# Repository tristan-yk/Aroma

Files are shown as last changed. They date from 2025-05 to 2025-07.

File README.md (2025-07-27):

# Aroma Control Board

<p align="center">
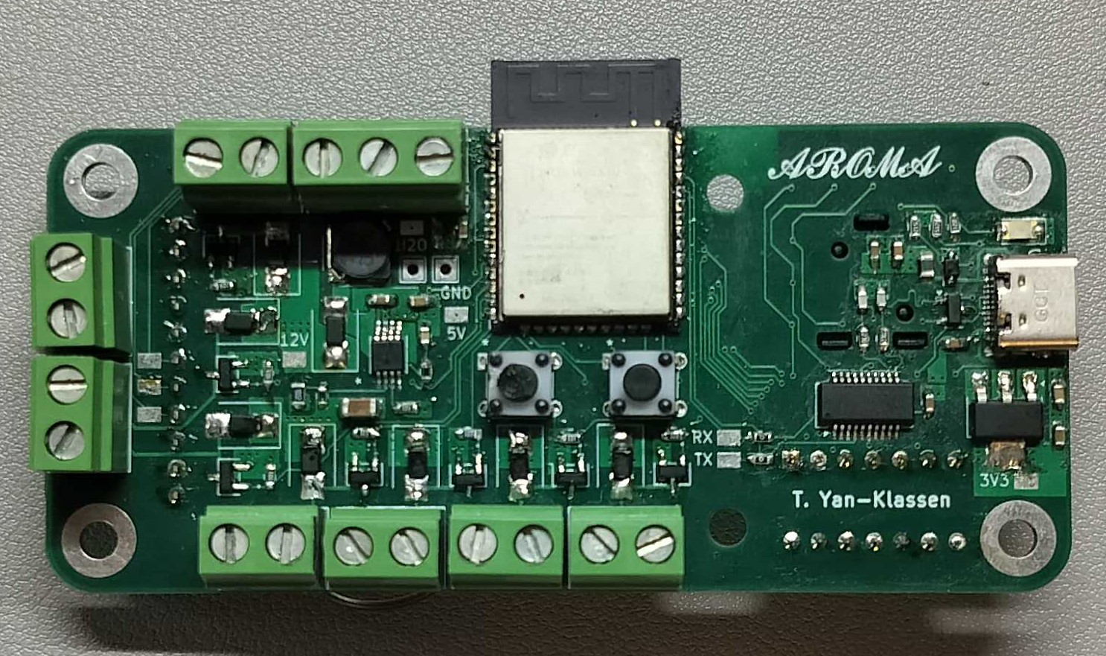
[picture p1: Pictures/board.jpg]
Aroma control board PCB
  
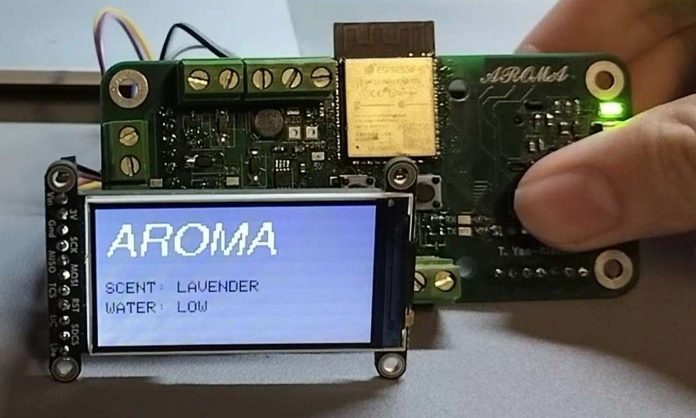
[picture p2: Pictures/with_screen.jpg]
Board with TFT screen attached
  
</p>

**Aroma Controller** is a compact ESP32 project that drives a multi‑scent diffuser with an intuitive on‑device UI. A five‑way joystick selects between an **OFF** state and several active scent profiles, while a small SPI TFT displays the current mode and status. The goal is a clean, responsive interface that runs untethered and can be extended with timers or profiles.

The firmware uses a debounced state machine so each joystick action cleanly toggles its corresponding scent. A simple analog water‑level input is monitored and shown on screen to avoid running dry. The display presents a title view and per‑scent screens with distinct themes, and draw calls are kept lightweight to minimize tearing on the SPI bus.

The board is powered and programmed over **USB‑C** for easy access, with programming handled by an onboard **USB‑to‑UART** converter. An onboard **boost converter** generates 12 V to drive **five pump channels** (five total scents), and a **5 V fan** automatically runs whenever any pump is active. The board also integrates the analog water sensor, debounced joystick input, and a color SPI TFT (ST7789, 1.9″ 320×170).

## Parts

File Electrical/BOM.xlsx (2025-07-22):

Id | Designator | Footprint | Quantity | Designation | Supplier and ref
1 | U12,U11,U7,U9,U10,U8,U6 | mosfet | 7 | BSR802NL6327HTSA1
2 | J2 | 691137710003 | 1 | 691137710003
3 | TP6,TX,5V,RX,TP8,12V,TP7,H2O,3V3 | S2751-46R | 9 | S2751-46R
4 | R5,R6 | R_0603_1608Metric | 2 | 27R
5 | J8,J9,J6,J7,J4,J5,J3 | 691137710002 | 7 | 691137710002
6 | D1 | LED_1206_3216Metric_Pad1.42x1.75mm_HandSolder | 1 | LED
7 | C17,C16 | C_0603_1608Metric_Pad1.08x0.95mm_HandSolder | 2 | 22u
8 | R26,R31,R28,R27,R11,R30,R13,R25,R29,R1,R24,R17,R15,R20,R8,R21,R16,R22,R23,R19,R7,R18 | R_0603_1608Metric | 22 | 10k
9 | D7,D6,D4,D9,D8,D11,D10,D5 | D_SMB | 8 | B260 | t
10 | SW1,SW2 | SW4_1825910-B_TEC | 2 | 1825910-6 | t
11 | D3 | SOT-23-3 | 1 | ~ | t
12 | L1 | IND_NP-100NC_SUM | 1 | 10u
13 | R9,R10 | R_0603_1608Metric | 2 | 0R
14 | C10,C9 | C_0603_1608Metric_Pad1.08x0.95mm_HandSolder | 2 | 47p
15 | IC1 | ESP32WROOM32EN8R2 | 1 | ESP32-WROOM-32E-N8R2 | t
16 | C8 | C_0603_1608Metric_Pad1.08x0.95mm_HandSolder | 1 | 4u7
17 | R12 | R_0603_1608Metric | 1 | 86k6
18 | C14 | C_0603_1608Metric_Pad1.08x0.95mm_HandSolder | 1 | 1n8
19 | U2 | boost | 1 | ADP1613ARMZ-R7 | t
20 | C15 | C_1206_3216Metric | 1 | 10u
21 | FB1 | L_0805_2012Metric | 1 | FerriteBead | t
22 | C2,C7,C11,C5,C22,C1,C19,C20,C18,C3,C21 | C_0603_1608Metric_Pad1.08x0.95mm_HandSolder | 11 | 100n
23 | R2 | R_0603_1608Metric | 1 | 150R
24 | GND,TP1 | TestPoint_THTPad_2.0x2.0mm_Drill1.0mm | 2 | TestPoint
25 | C6 | C_0603_1608Metric_Pad1.08x0.95mm_HandSolder | 1 | 10n
26 | C4 | C_0603_1608Metric_Pad1.08x0.95mm_HandSolder | 1 | 1u
27 | D2 | ESD5V0D3-TP | 1 | ESD5V0D3-TP | t
28 | U3 | SOT-223-3_TabPin2 | 1 | AMS1117-3.3 | t
29 | R4,R3 | R_0603_1608Metric | 2 | 5k1
30 | J1 | GCT_USB4105-GF-A | 1 | USB4105-GF-A
31 | C13 | C_0603_1608Metric_Pad1.08x0.95mm_HandSolder | 1 | 33n
32 | U1 | SSOP-20_3.9x8.7mm_P0.635mm | 1 | FT231XS | t
33 | R14 | R_0603_1608Metric | 1 | 22k
34 | C12 | C_0603_1608Metric_Pad1.08x0.95mm_HandSolder | 1 | 10u
35 | SW3 | SW_JS5208 | 1 | JS5208 | t
36 | Q2,Q1 | SOT-23 | 2 | SS8050 | t
37 | U5 | LCD_ST7789 | 1 | ~ | t
38 | U4 | DIP-14_W7.62mm | 1 | 74HC14 | t

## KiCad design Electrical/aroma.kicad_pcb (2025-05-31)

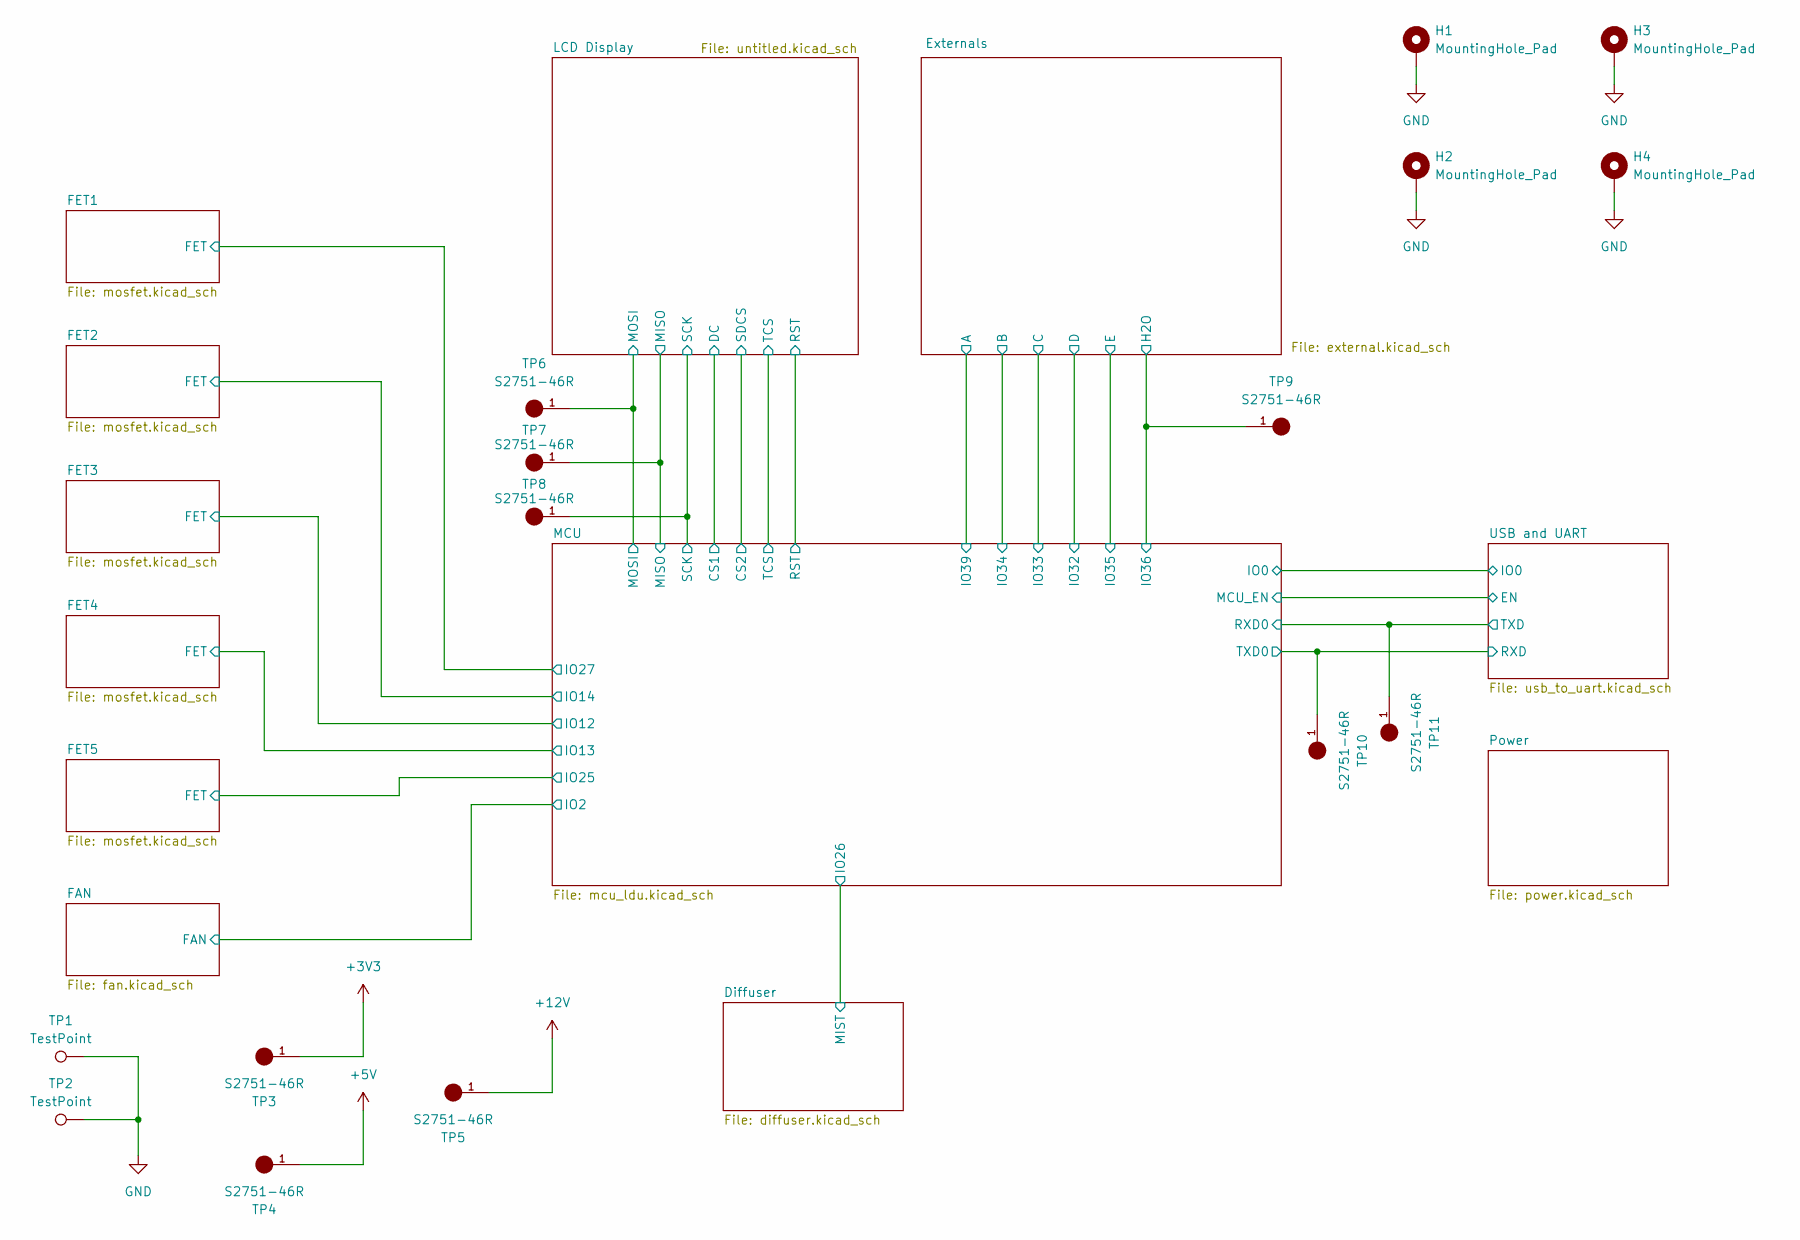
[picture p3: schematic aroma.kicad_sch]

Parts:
H1, H2, H3, H4: MountingHole_Pad; MountingHole_3.5mm_Pad
TP1, TP2: TestPoint; TestPoint_THTPad_2.0x2.0mm_Drill1.0mm
TP3, TP4, TP5, TP6, TP7, TP8, TP9, TP10, TP11: S2751-46R; PARTREV 1

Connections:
/LCD Display/MISO: TP7.1; also elsewhere on the board
/LCD Display/MOSI: TP6.1; also elsewhere on the board
/LCD Display/SCK: TP8.1; also elsewhere on the board
GND: H1.1, H2.1, H3.1, H4.1, TP1.1, TP2.1; also elsewhere on the board

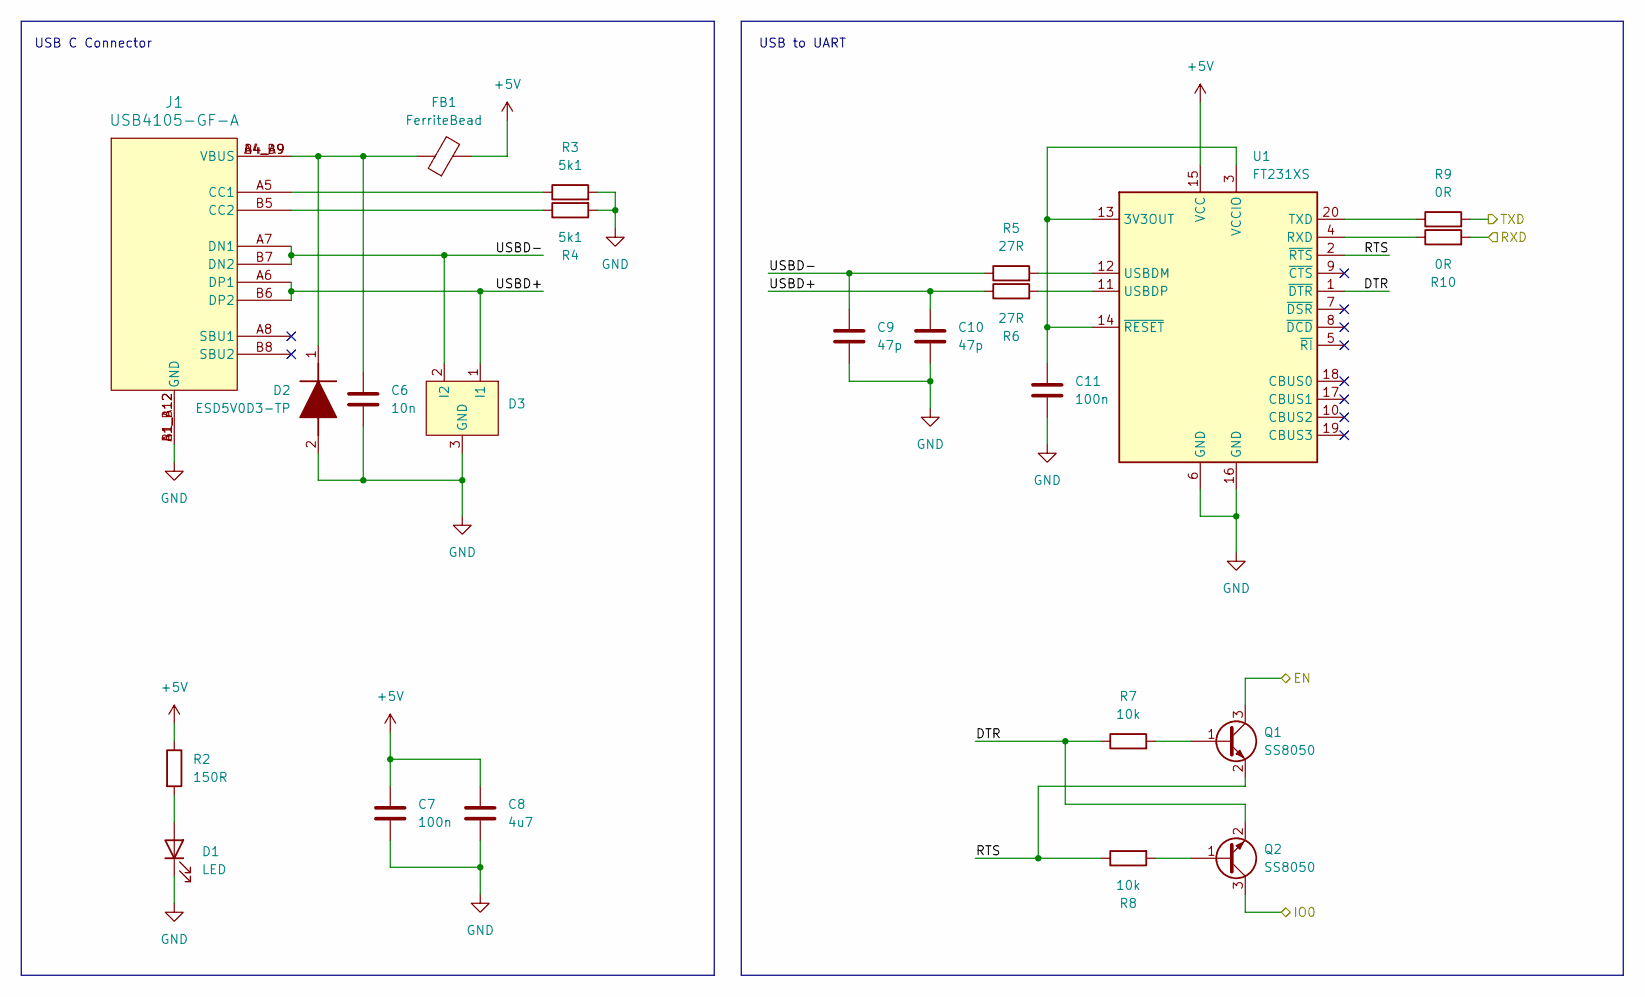
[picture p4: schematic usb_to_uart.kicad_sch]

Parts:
C6: 10n; C_0603_1608Metric_Pad1.08x0.95mm_HandSolder
C7, C11: 100n; C_0603_1608Metric_Pad1.08x0.95mm_HandSolder
C8: 4u7; C_0603_1608Metric_Pad1.08x0.95mm_HandSolder
C9, C10: 47p; C_0603_1608Metric_Pad1.08x0.95mm_HandSolder
D1: LED; LED_1206_3216Metric_Pad1.42x1.75mm_HandSolder
D2: ESD5V0D3-TP; Mouser Part Number 833-ESD5V0D3-TP
D3: SOT-23-3
FB1: FerriteBead; L_0805_2012Metric
J1: USB4105-GF-A; GCT_USB4105-GF-A
Q1, Q2: SS8050; SOT-23
R2: 150R; R_0603_1608Metric
R3, R4: 5k1; R_0603_1608Metric
R5, R6: 27R; R_0603_1608Metric
R7, R8: 10k; R_0603_1608Metric
R9, R10: 0R; R_0603_1608Metric
U1: FT231XS; SSOP-20_3.9x8.7mm_P0.635mm

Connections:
+5V: C7.1, C8.1, FB1.2, R2.1, U1.15 (VCC); also elsewhere on the board
/MCU/IO0: Q2.3 (C); also elsewhere on the board
/MCU/MCU_EN: Q1.3 (C); also elsewhere on the board
/MCU/RXD0: R9.2; also elsewhere on the board
/MCU/TXD0: R10.2; also elsewhere on the board
/USB and UART/DTR: Q2.2 (E), R7.1, U1.1 (~DTR)
/USB and UART/RTS: Q1.2 (E), R8.1, U1.2 (~RTS)
/USB and UART/USBD+: C10.1, D3.1 (I1), J1.A6 (DP1), J1.B6 (DP2), R6.1
/USB and UART/USBD-: C9.1, D3.2 (I2), J1.A7 (DN1), J1.B7 (DN2), R5.1
GND: C6.2, C7.2, C8.2, C9.2, C10.2, C11.2, D1.1 (K), D2.2 (A), D3.3 (GND), J1.A1_B12 (GND), J1.B1_A12 (GND), R3.2, R4.2, U1.6 (GND), U1.16 (GND); also elsewhere on the board
unnamed: D1.2 (A), R2.2
unnamed: C6.1, D2.1 (K), FB1.1, J1.A4_B9 (VBUS), J1.B4_A9 (VBUS)
unnamed: J1.A5 (CC1), R3.1
unnamed: J1.B5 (CC2), R4.1
unnamed: Q1.1 (B), R7.2
unnamed: Q2.1 (B), R8.2
unnamed: C11.1, U1.3 (VCCIO), U1.13 (3V3OUT), U1.14 (~RESET)
unnamed: R10.1, U1.4 (RXD)
unnamed: R9.1, U1.20 (TXD)
unnamed: R5.2, U1.12 (USBDM)
unnamed: R6.2, U1.11 (USBDP)

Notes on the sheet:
USB to UART
USB C Connector

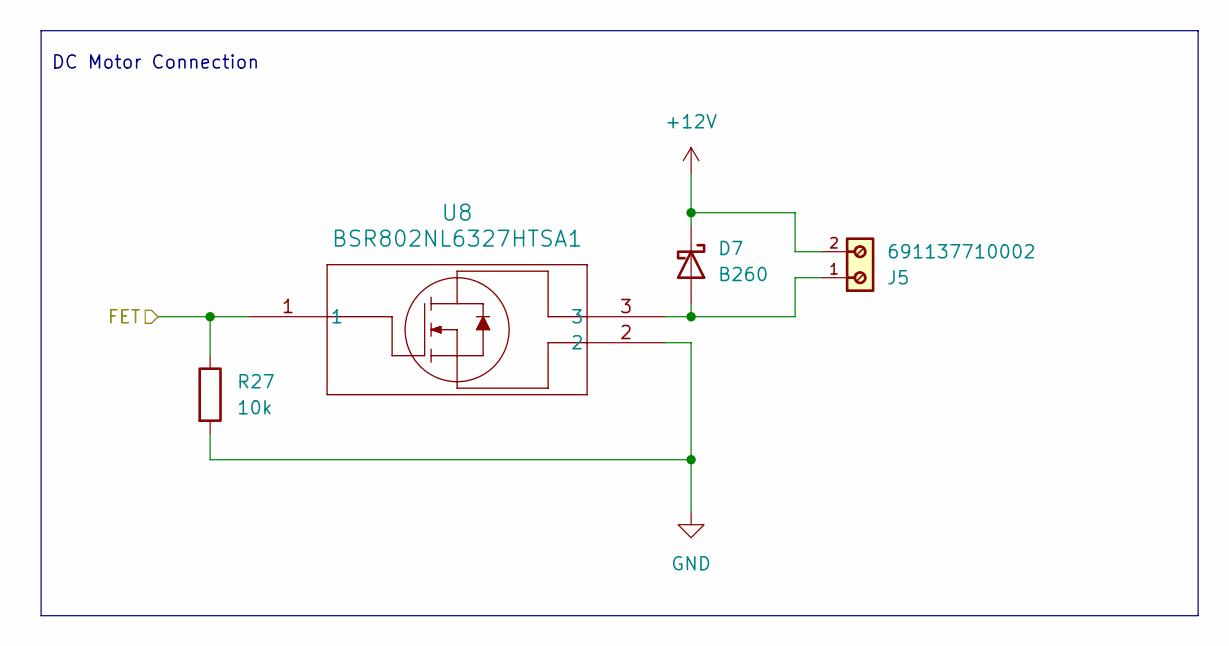
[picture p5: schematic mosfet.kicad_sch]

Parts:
D7: B260; D_SMB
J5: 691137710002
R27: 10k; R_0603_1608Metric
U8: BSR802NL6327HTSA1; mosfet

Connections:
+12V: D7.1 (K), J5.2; also elsewhere on the board
/FET3/FET: R27.1, U8.1; also elsewhere on the board
GND: R27.2, U8.2; also elsewhere on the board
unnamed: D7.2 (A), J5.1, U8.3

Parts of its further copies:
D5, D6, D8, D9: B260; D_SMB
J3, J4, J6, J7: 691137710002
R25, R26, R28, R29: 10k; R_0603_1608Metric
U6, U7, U9, U10: BSR802NL6327HTSA1; mosfet

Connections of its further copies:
+12V: D5.1 (K), D6.1 (K), D8.1 (K), D9.1 (K), J3.2, J4.2, J6.2, J7.2; also elsewhere on the board
/FET1/FET: R25.1, U6.1; also elsewhere on the board
/FET2/FET: R26.1, U7.1; also elsewhere on the board
/FET4/FET: R28.1, U9.1; also elsewhere on the board
/FET5/FET: R29.1, U10.1; also elsewhere on the board
GND: R25.2, R26.2, R28.2, R29.2, U6.2, U7.2, U9.2, U10.2; also elsewhere on the board
unnamed: D5.2 (A), J3.1, U6.3
unnamed: D6.2 (A), J4.1, U7.3
unnamed: D8.2 (A), J6.1, U9.3
unnamed: D9.2 (A), J7.1, U10.3

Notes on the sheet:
DC Motor Connection

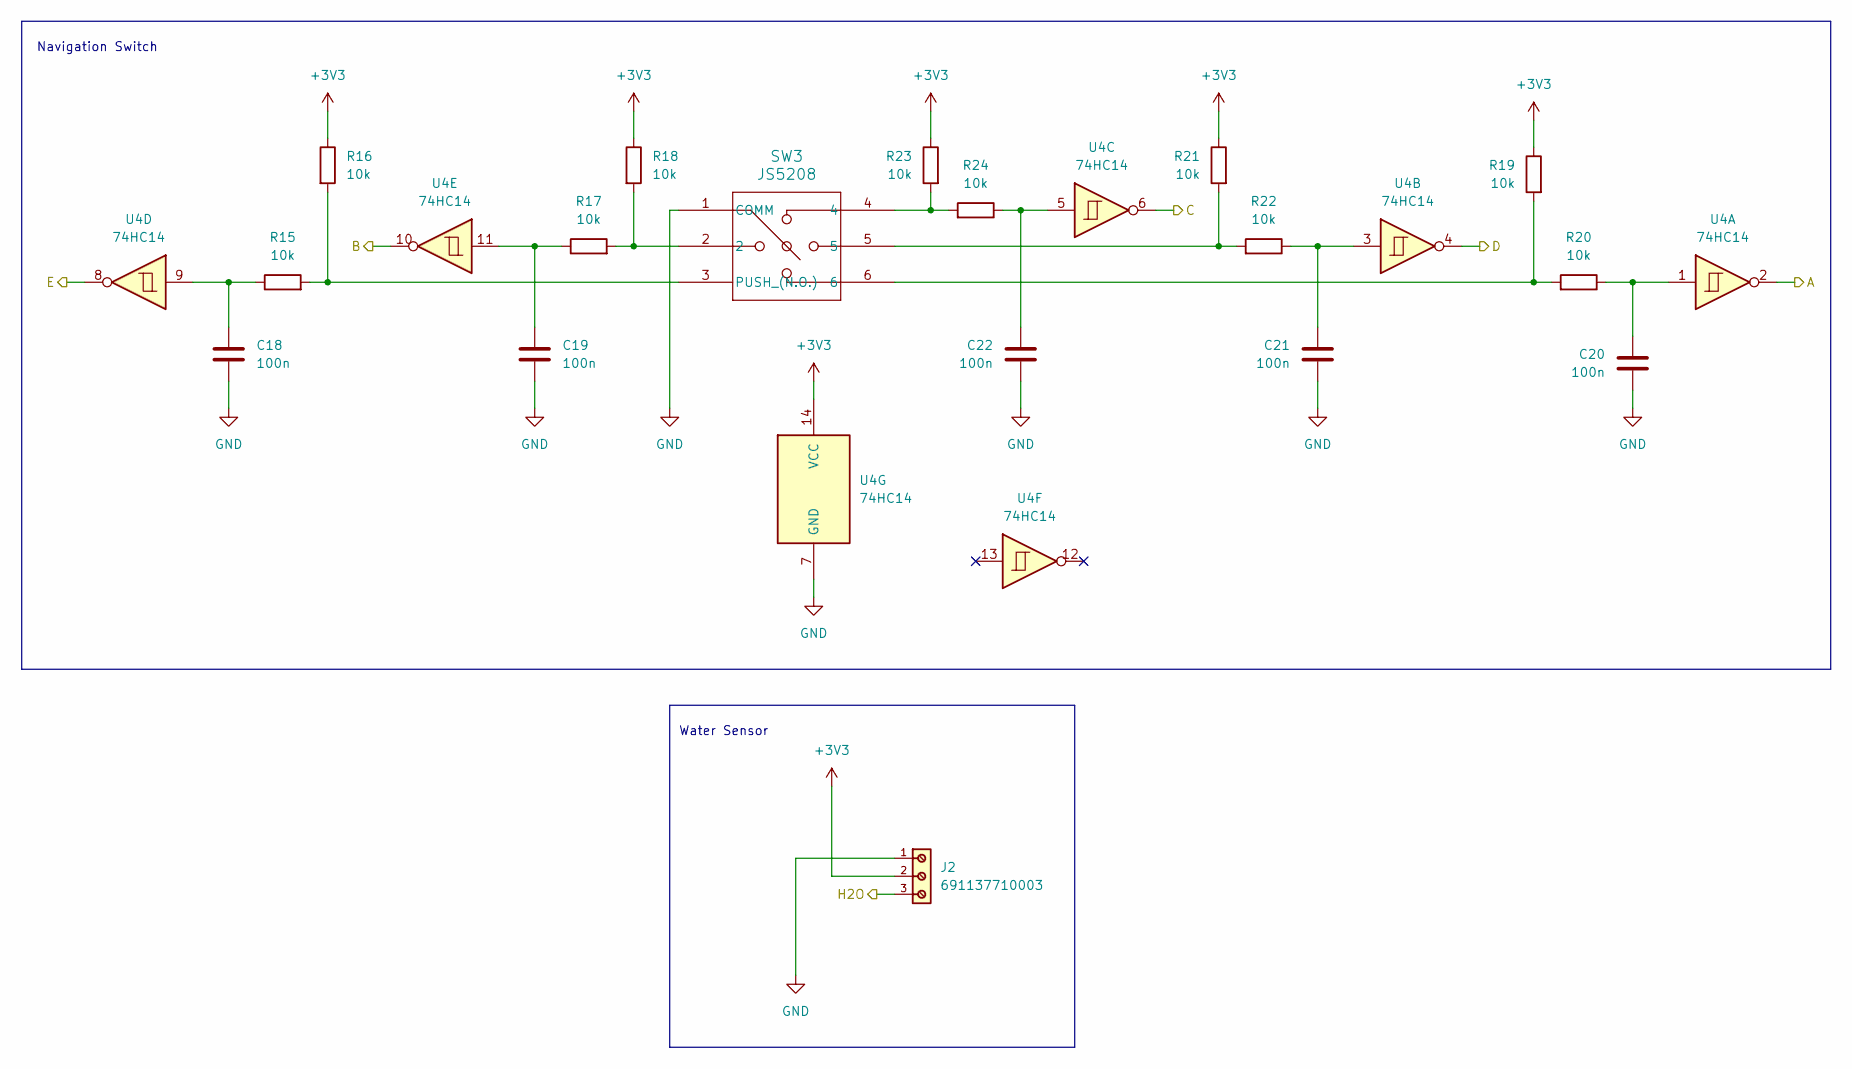
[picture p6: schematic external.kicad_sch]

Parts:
C18, C19, C20, C21, C22: 100n; C_0603_1608Metric_Pad1.08x0.95mm_HandSolder
J2: 691137710003
R15, R16, R17, R18, R19, R20, R21, R22, R23, R24: 10k; R_0603_1608Metric
SW3: JS5208; SW_JS5208
U4: 74HC14; DIP-14_W7.62mm

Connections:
+3V3: J2.2, R16.1, R18.1, R19.1, R21.1, R23.1, U4.14 (VCC); also elsewhere on the board
/Externals/A: U4.2; also elsewhere on the board
/Externals/B: U4.10; also elsewhere on the board
/Externals/C: U4.6; also elsewhere on the board
/Externals/D: U4.4; also elsewhere on the board
/Externals/E: U4.8; also elsewhere on the board
/Externals/H2O: J2.3; also elsewhere on the board
GND: C18.2, C19.2, C20.2, C21.2, C22.2, J2.1, SW3.1 (COMM), U4.7 (GND); also elsewhere on the board
unnamed: C18.1, R15.1, U4.9
unnamed: C19.1, R17.1, U4.11
unnamed: C20.1, R20.1, U4.1
unnamed: C21.1, R22.1, U4.3
unnamed: C22.1, R24.1, U4.5
unnamed: R17.2, R18.2, SW3.2
unnamed: R19.2, R20.2, SW3.6
unnamed: R21.2, R22.2, SW3.5
unnamed: R23.2, R24.2, SW3.4
unnamed: R15.2, R16.2, SW3.3 (PUSH_(N.O.))

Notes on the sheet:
Navigation Switch
Water Sensor

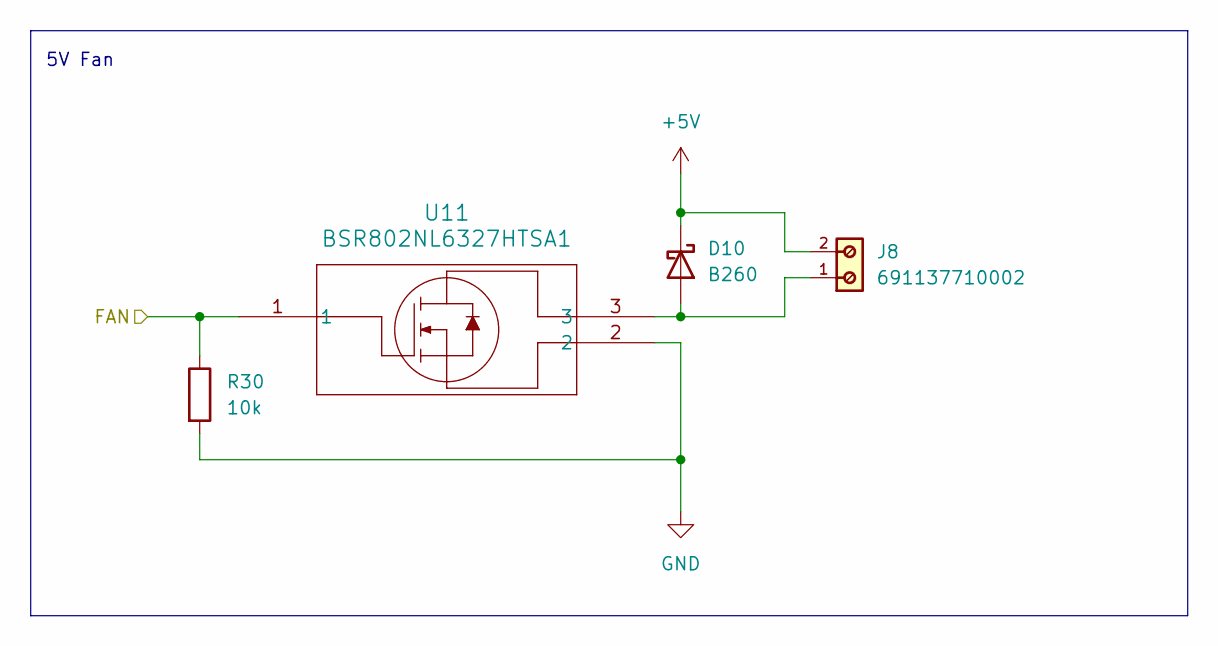
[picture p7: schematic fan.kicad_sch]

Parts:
D10: B260; D_SMB
J8: 691137710002
R30: 10k; R_0603_1608Metric
U11: BSR802NL6327HTSA1; mosfet

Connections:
+5V: D10.1 (K), J8.2; also elsewhere on the board
/FAN/FAN: R30.1, U11.1; also elsewhere on the board
GND: R30.2, U11.2; also elsewhere on the board
unnamed: D10.2 (A), J8.1, U11.3

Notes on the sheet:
5V Fan

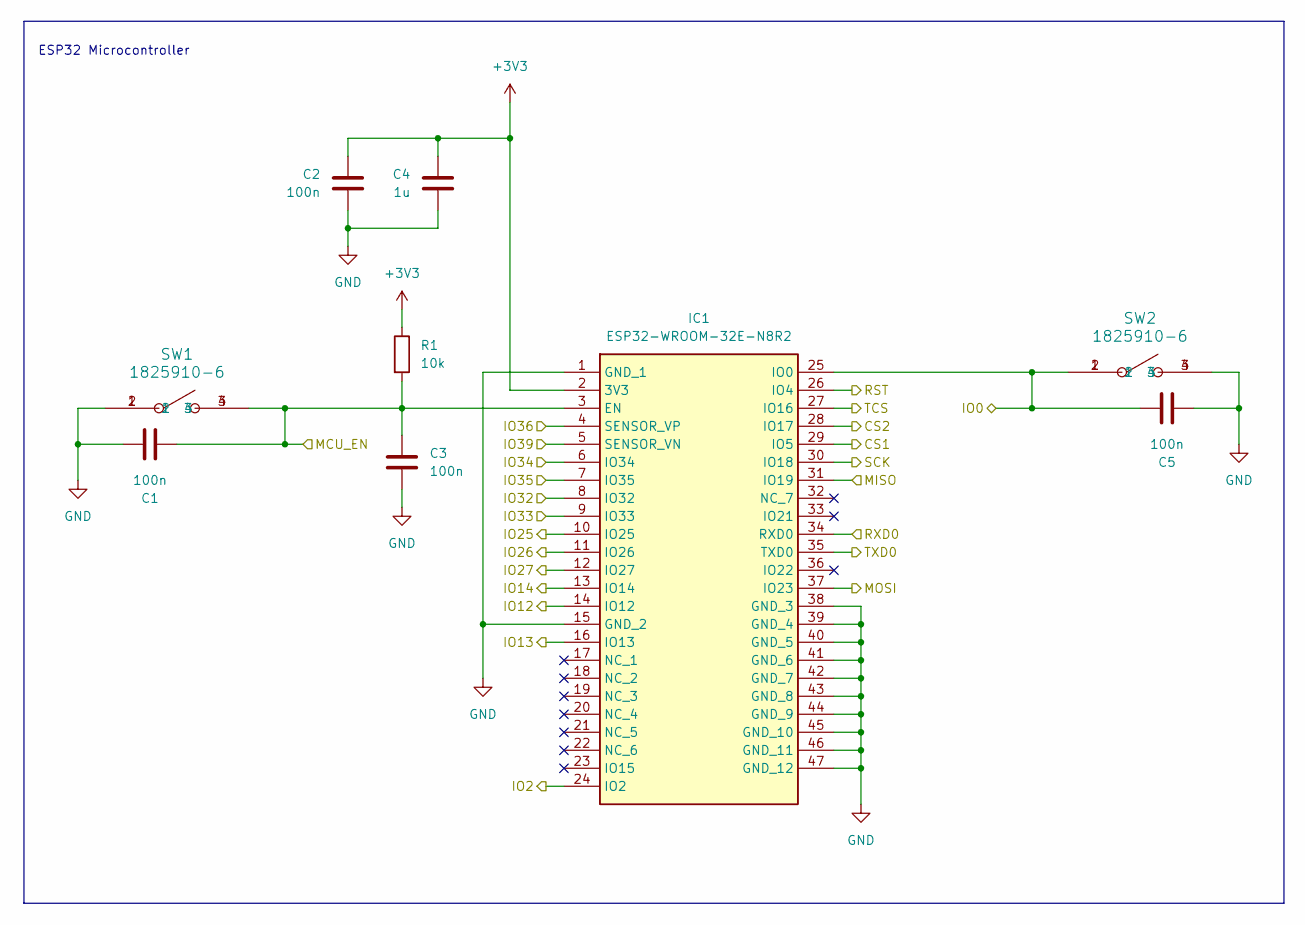
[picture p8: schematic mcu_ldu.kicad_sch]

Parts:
C1, C2, C3, C5: 100n; C_0603_1608Metric_Pad1.08x0.95mm_HandSolder
C4: 1u; C_0603_1608Metric_Pad1.08x0.95mm_HandSolder
IC1: ESP32-WROOM-32E-N8R2; ESP32WROOM32EN8R2; Mouser Part Number 356-ESP32WRM32EN8R2
R1: 10k; R_0603_1608Metric
SW1, SW2: 1825910-6; SW4_1825910-B_TEC

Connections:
+3V3: C2.1, C4.1, IC1.2 (3V3), R1.1; also elsewhere on the board
/Diffuser/MIST: IC1.11 (IO26); also elsewhere on the board
/Externals/A: IC1.5 (SENSOR_VN); also elsewhere on the board
/Externals/B: IC1.6 (IO34); also elsewhere on the board
/Externals/C: IC1.9 (IO33); also elsewhere on the board
/Externals/D: IC1.8 (IO32); also elsewhere on the board
/Externals/E: IC1.7 (IO35); also elsewhere on the board
/Externals/H2O: IC1.4 (SENSOR_VP); also elsewhere on the board
/FAN/FAN: IC1.24 (IO2); also elsewhere on the board
/FET1/FET: IC1.12 (IO27); also elsewhere on the board
/FET2/FET: IC1.13 (IO14); also elsewhere on the board
/FET3/FET: IC1.14 (IO12); also elsewhere on the board
/FET4/FET: IC1.16 (IO13); also elsewhere on the board
/FET5/FET: IC1.10 (IO25); also elsewhere on the board
/LCD Display/DC: IC1.29 (IO5); also elsewhere on the board
/LCD Display/MISO: IC1.31 (IO19); also elsewhere on the board
/LCD Display/MOSI: IC1.37 (IO23); also elsewhere on the board
/LCD Display/RST: IC1.26 (IO4); also elsewhere on the board
/LCD Display/SCK: IC1.30 (IO18); also elsewhere on the board
/LCD Display/SDCS: IC1.28 (IO17); also elsewhere on the board
/LCD Display/TCS: IC1.27 (IO16); also elsewhere on the board
/MCU/IO0: C5.2, IC1.25 (IO0), SW2.1, SW2.2; also elsewhere on the board
/MCU/MCU_EN: C1.2, C3.1, IC1.3 (EN), R1.2, SW1.3, SW1.4; also elsewhere on the board
/MCU/RXD0: IC1.34 (RXD0); also elsewhere on the board
/MCU/TXD0: IC1.35 (TXD0); also elsewhere on the board
GND: C1.1, C2.2, C3.2, C4.2, C5.1, IC1.1 (GND_1), IC1.15 (GND_2), IC1.38 (GND_3), IC1.39 (GND_4), IC1.40 (GND_5), IC1.41 (GND_6), IC1.42 (GND_7), IC1.43 (GND_8), IC1.44 (GND_9), IC1.45 (GND_10), IC1.46 (GND_11), IC1.47 (GND_12), SW1.1, SW1.2, SW2.3, SW2.4; also elsewhere on the board

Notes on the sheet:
ESP32 Microcontroller

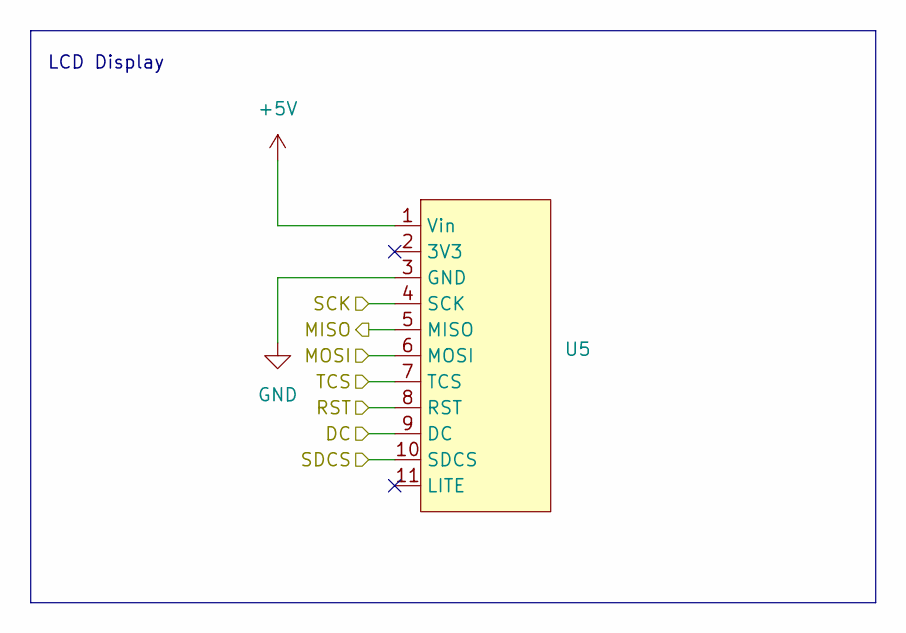
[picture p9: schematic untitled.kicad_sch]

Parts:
U5: LCD_ST7789

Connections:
+5V: U5.1 (Vin); also elsewhere on the board
/LCD Display/DC: U5.9 (DC); also elsewhere on the board
/LCD Display/MISO: U5.5 (MISO); also elsewhere on the board
/LCD Display/MOSI: U5.6 (MOSI); also elsewhere on the board
/LCD Display/RST: U5.8 (RST); also elsewhere on the board
/LCD Display/SCK: U5.4 (SCK); also elsewhere on the board
/LCD Display/SDCS: U5.10 (SDCS); also elsewhere on the board
/LCD Display/TCS: U5.7 (TCS); also elsewhere on the board
GND: U5.3 (GND); also elsewhere on the board

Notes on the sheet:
LCD Display

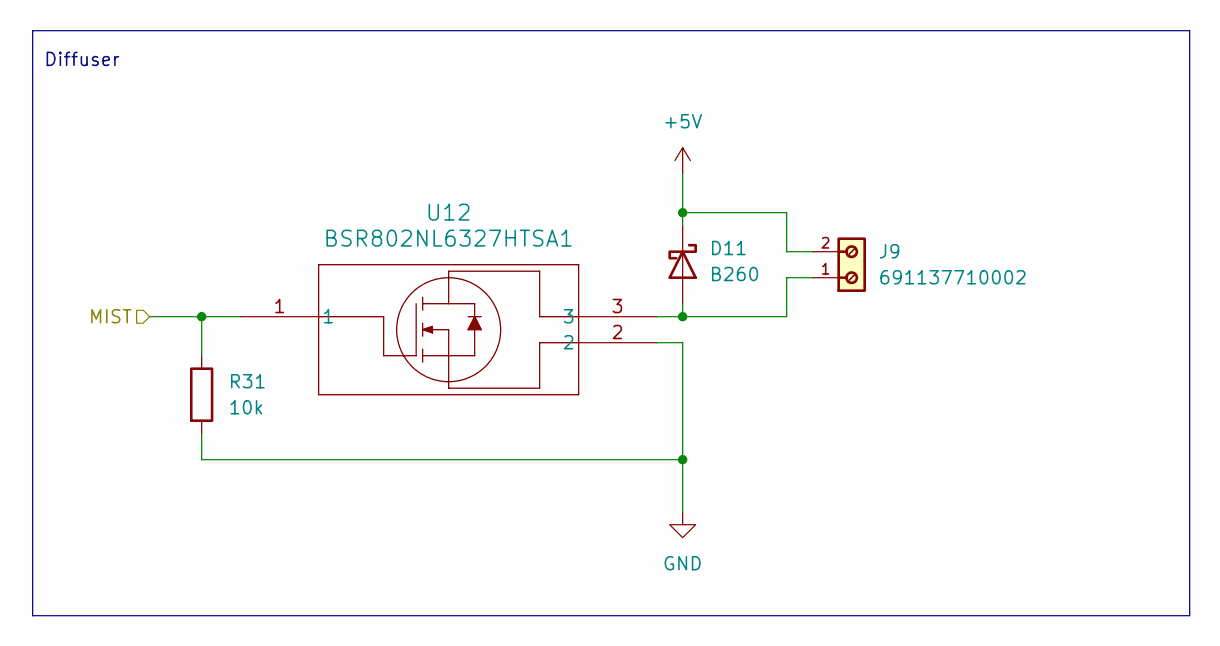
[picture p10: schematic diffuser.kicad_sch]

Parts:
D11: B260; D_SMB
J9: 691137710002
R31: 10k; R_0603_1608Metric
U12: BSR802NL6327HTSA1; mosfet

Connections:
+5V: D11.1 (K), J9.2; also elsewhere on the board
/Diffuser/MIST: R31.1, U12.1; also elsewhere on the board
GND: R31.2, U12.2; also elsewhere on the board
unnamed: D11.2 (A), J9.1, U12.3

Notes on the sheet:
Diffuser

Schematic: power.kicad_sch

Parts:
C12: 10u; C_0603_1608Metric_Pad1.08x0.95mm_HandSolder
C13: 33n; C_0603_1608Metric_Pad1.08x0.95mm_HandSolder
C14: 1n8; C_0603_1608Metric_Pad1.08x0.95mm_HandSolder
C15: 10u; C_1206_3216Metric
C16, C17: 22u; C_0603_1608Metric_Pad1.08x0.95mm_HandSolder
D4: B260; D_SMB
L1: 10u; IND_NP-100NC_SUM
R11, R13: 10k; R_0603_1608Metric
R12: 86k6; R_0603_1608Metric
R14: 22k; R_0603_1608Metric
U2: ADP1613ARMZ-R7; boost
U3: AMS1117-3.3; SOT-223-3_TabPin2

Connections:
+3V3: C17.1, U3.2 (VO); also elsewhere on the board
+5V: C12.1, C16.1, L1.1, R11.1, U2.6 (VIN), U3.3 (VI); also elsewhere on the board
+12V: C15.1, D4.1 (K), R12.1; also elsewhere on the board
GND: C12.2, C13.2, C14.2, C15.2, C16.2, C17.2, R13.2, U2.4 (GND), U2.7 (FREQ), U3.1 (GND); also elsewhere on the board
unnamed: C14.1, R14.2
unnamed: D4.2 (A), L1.2, U2.5 (SW)
unnamed: R14.1, U2.1 (COMP)
unnamed: R11.2, U2.3 (EN)
unnamed: R12.2, R13.1, U2.2 (FB)
unnamed: C13.1, U2.8 (SS)

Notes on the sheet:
LDO
12V Boost

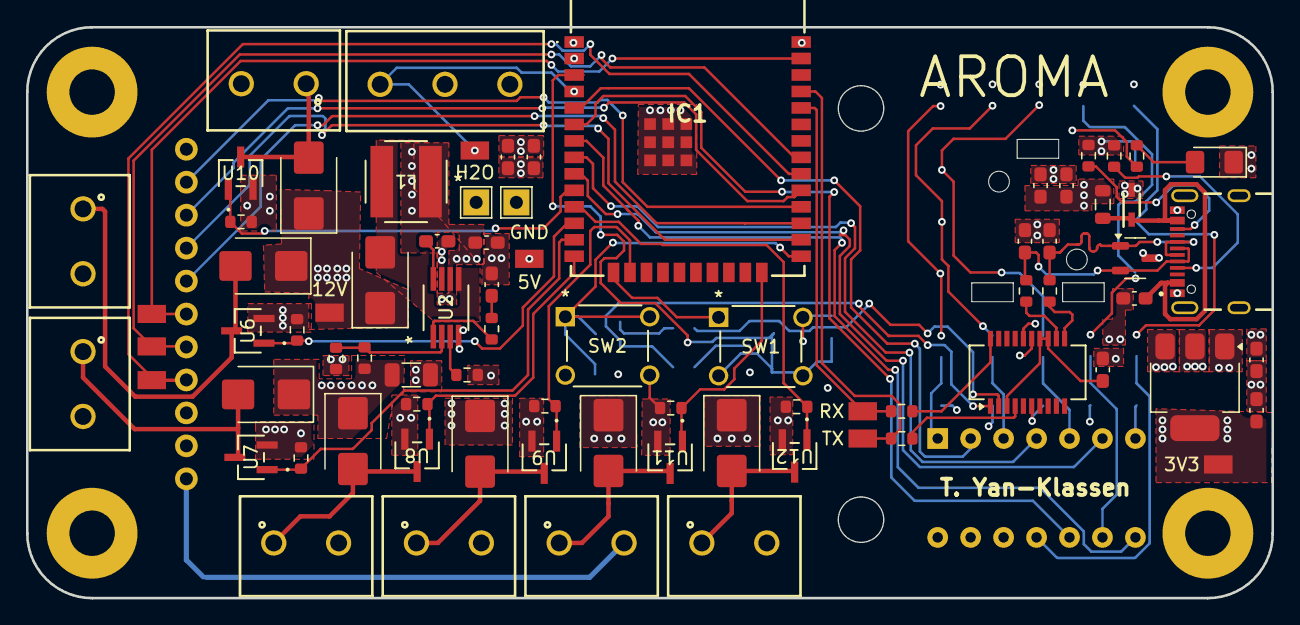
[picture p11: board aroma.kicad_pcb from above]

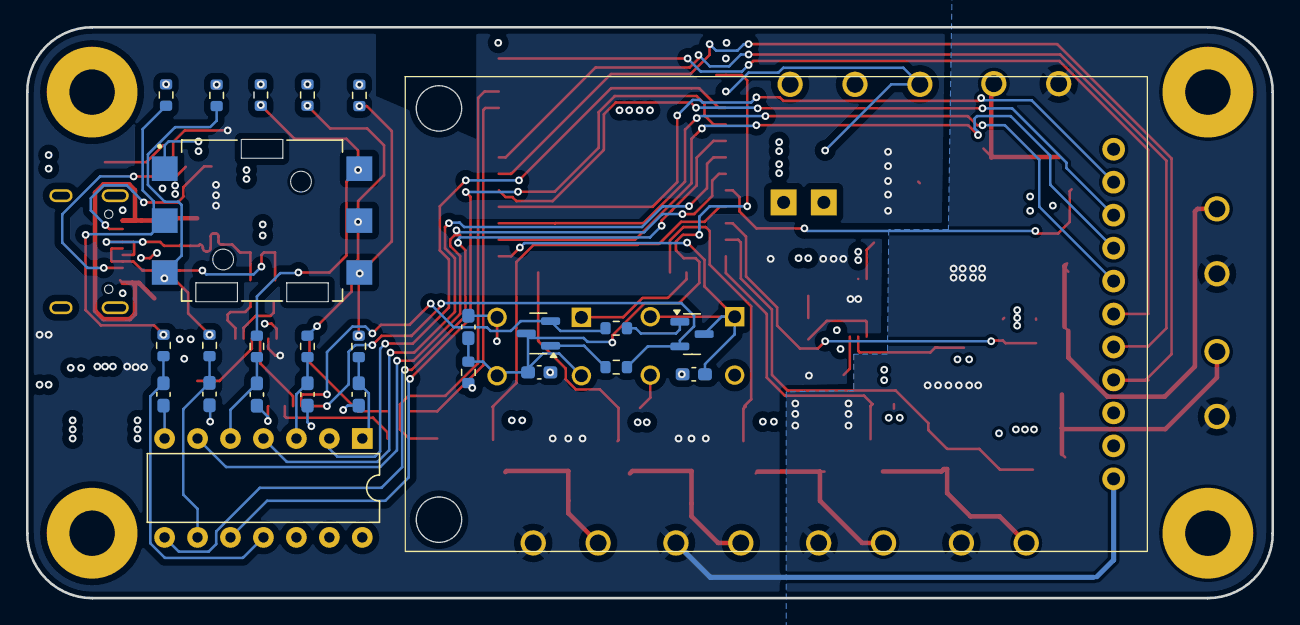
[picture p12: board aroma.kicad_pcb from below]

Board: 4 copper layers, 96.0 x 44.0 mm, 108 parts (26 on the bottom side), 66 nets.

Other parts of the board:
3V3, 5V, 12V: S2751-46R
GND: TestPoint; TestPoint_THTPad_2.0x2.0mm_Drill1.0mm
H2O: S2751-46R
RX: S2751-46R
TX: S2751-46R

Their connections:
+3V3: 3V3.1; also elsewhere on the board
+5V: 5V.1; also elsewhere on the board
+12V: 12V.1; also elsewhere on the board
/Externals/H2O: H2O.1; also elsewhere on the board
/MCU/RXD0: RX.1; also elsewhere on the board
/MCU/TXD0: TX.1; also elsewhere on the board
GND: GND.1; also elsewhere on the board

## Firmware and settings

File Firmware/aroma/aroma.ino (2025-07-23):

#include "state.h"
#include "display.h"

SystemState currentState = OFF;
unsigned long lastPrintTime = 0;
const unsigned long printInterval = 1000;  // 1 second

void setup() {
  delay(200);
  Serial.begin(115200);
  setupStateControl();
  currentState = OFF;
  setupDisplay();

}

void loop() {
  updateState(currentState);
  applyState(currentState);

  unsigned long now = millis();
  if (now - lastPrintTime >= printInterval) {
    lastPrintTime = now;

    Serial.print("Current state: ");
    Serial.println(stateToString(currentState));

    displayState(currentState);  // now uses display.cpp
  }
}

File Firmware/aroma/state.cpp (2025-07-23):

#include "state.h"

// Adjust these to your actual pins
const int SWITCH_PINS[5] = {39, 34, 33, 32, 35};
const int OUTPUT_PINS[5] = {25, 27, 14, 12, 13};
const int FAN_PIN = 2;

static bool lastPressed[5] = {false, false, false, false, false};  // edge detection

const char* stateToString(SystemState state) {
  switch (state) {
    case OFF:      return "OFF";
    case ACTIVE_1: return "ACTIVE_1";
    case ACTIVE_2: return "ACTIVE_2";
    case ACTIVE_3: return "ACTIVE_3";
    case ACTIVE_4: return "ACTIVE_4";
    case ACTIVE_5: return "ACTIVE_5";
    default:       return "UNKNOWN";
  }
}

void setupStateControl() {
  for (int i = 0; i < 5; i++) {
    pinMode(SWITCH_PINS[i], INPUT_PULLUP);
    pinMode(OUTPUT_PINS[i], OUTPUT);
    digitalWrite(OUTPUT_PINS[i], LOW); // start OFF
  }
  for (int i = 0; i < 5; i++) {
    lastPressed[i] = (digitalRead(SWITCH_PINS[i]) == LOW);
  }
  pinMode(FAN_PIN, OUTPUT);
  digitalWrite(FAN_PIN, LOW);
}

void updateState(SystemState& state) {
  for (int i = 0; i < 5; i++) {
    bool pressed = (digitalRead(SWITCH_PINS[i]) == LOW);

    if (pressed && !lastPressed[i]) {
      if (state == (SystemState)(ACTIVE_1 + i)) {
        state = OFF;
      } else {
        state = (SystemState)(ACTIVE_1 + i);
      }
    }

    lastPressed[i] = pressed;
  }
}

void applyState(SystemState state) {
  for (int i = 0; i < 5; i++) {
    digitalWrite(OUTPUT_PINS[i], LOW);
  }
  digitalWrite(FAN_PIN, LOW);

  

  switch (state) {
    case ACTIVE_1: 
      digitalWrite(OUTPUT_PINS[0], HIGH); 
      digitalWrite(FAN_PIN, HIGH);
      break;
    case ACTIVE_2: 
      digitalWrite(OUTPUT_PINS[1], HIGH); 
      digitalWrite(FAN_PIN, HIGH);
      break;
    case ACTIVE_3: 
      digitalWrite(OUTPUT_PINS[2], HIGH); 
      digitalWrite(FAN_PIN, HIGH);
      break;
    case ACTIVE_4: 
      digitalWrite(OUTPUT_PINS[3], HIGH);
      digitalWrite(FAN_PIN, HIGH);
      break;
    case ACTIVE_5: 
      digitalWrite(OUTPUT_PINS[4], HIGH); 
      digitalWrite(FAN_PIN, HIGH);
      break;
    case OFF:
      break;
    default: 
      break;
  }

}

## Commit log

2025-05-20 LCD Display
    [aroma.kicad_sch, mcu_ldu.kicad_sch, mosfet.kicad_sch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]
2025-05-30 passed drc (somehow)
    board routing is def cooked
    verify:
    - boost layout
    - usb terminal layout
    [aroma.kicad_pcb, aroma.kicad_sch, diffuser.kicad_sch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]
2025-05-31 impedance matching
    [aroma.kicad_pcb]
2025-05-31 fix prelims
    [aroma.kicad_pcb]
2025-05-31 gerber fix
    [aroma-B_Cu.gbl, aroma-B_Mask.gbs, aroma-B_Paste.gbp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]
2025-07-22 pump selection code
